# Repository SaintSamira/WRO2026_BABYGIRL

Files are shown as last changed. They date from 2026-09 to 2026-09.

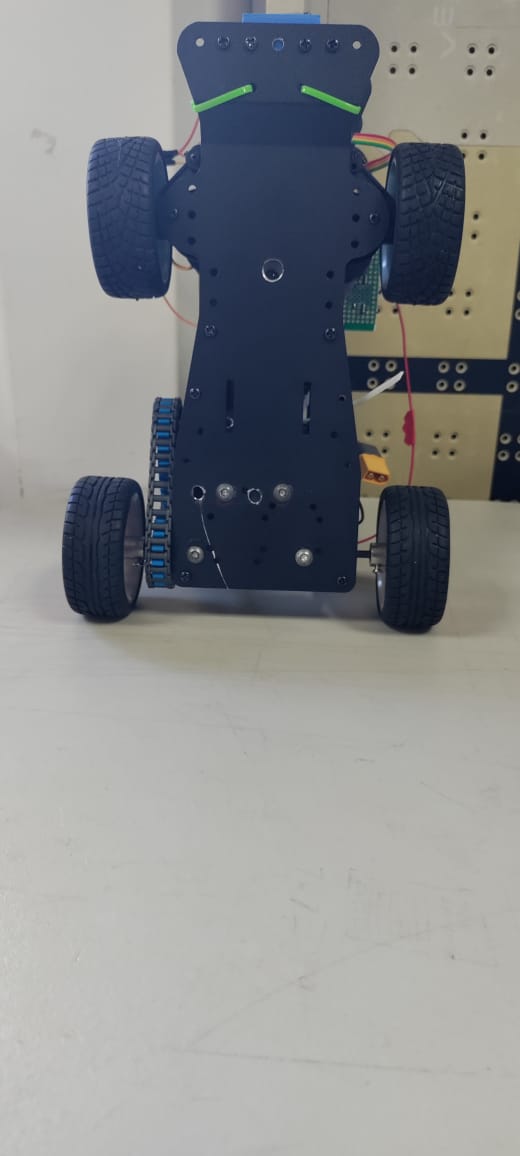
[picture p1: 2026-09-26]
v-photos/bottom.jpg

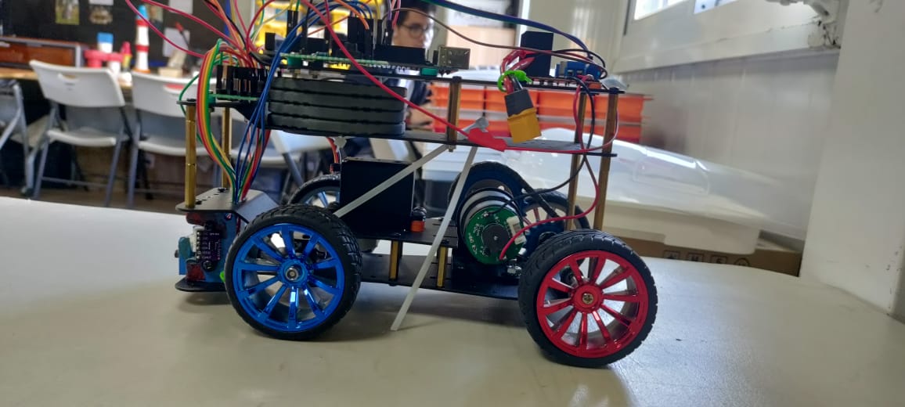
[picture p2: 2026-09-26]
v-photos/left.jpg

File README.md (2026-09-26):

# WRO Future Engineers 2026 — US Open
Autonomous self-driving vehicle engineering repository for the World Robot Olympiad Future Engineers category.
- Team: Bianca Polato & Samira Santos 
- Coach: Julian Vigil School: Howard Academy (Panama) 
- Event: WRO Future Engineers — US Open 2026
---

## Table of Contents
1. Team Introduction
2. The Challenge
3. Repository Structure
4. Mechanical Design
5. Electronics & Power Distribution
6. Software & Navigation Logic

## Team Introduction
Our team is composed of two members, working under the guidance of our coach, Julian Vigil.

- Bianca Polato - *Team Captain & Mechanical Lead*: Responsible for the physical build of the robot, including chassis assembly, mechanical integration, and hands-on electronics work such as soldering and wiring connections.
- Samira Santos - *Software Lead & Electronics Planning*: Responsible for programming the robot's control logic and computer vision, as well as planning the electronics architecture that Bianca implements physically.

This is our third year competing in WRO Future Engineers, and our first time qualifying for the Open. This program has always been, for us, about the process of learning: refining engineering reasoning, testing rigorously, and improving through iteration, rather than solely about the outcome of winning

## The Challenge
WRO Future Engineers challenges teams to design, build, and program a fully autonomous vehicle capable of navigating a reconfigurable race track without any human intervention or remote control once a round begins. The competition includes:
- **Open Challenge:** the vehicle must complete three consecutive laps around a track with a variable-size inner section, staying within the track boundaries.
- **Obstacle Challenge:** in addition to completing laps, the vehicle must identify and correctly respond to red and green traffic pillars along the track, and execute a parallel parking maneuver.
- **Suprise Challenge:** finally there was a recent addition to the rules. We are not sure on how what it is, but what we do know is that it involes a pedestrian cross walk.

Our current development priority is achieving a reliable, complete lap cycle in the Open Challenge before moving on to obstacle detection and parking.

## Repositiry Structure
- Model: includes all the digital models of the 3D printed bases we used.
- Schemes: includes a wiring diagrm of the electricl components of our vehicle.
- Src: includes the code we used for the detection and movement of the component in our vehicle
- t-photos: includes 2 fotos of the team.
- v-photos: includes fotos of the vehicle for different points of views.
- video: includes the car doing one lap.

## Mechanical Design
### Chassis
The V2.0 chassis is built on a modified metal car-building base kit (Olibots Arduino Advanced), which has been extensively adapted from its original configuration. This represents a complete departure from the LEGO SPIKE-based construction used in our earlier versions (V1.0 and V1.5), transitioning the team fully to open-source hardware and metal components.The wheels, steering servo, and L298N H-bridge motor driver were included with the Olibots kit. The metal axle and gears were reused from the school’s VEX V5 program.

The main structure consists of three metal plates connected by metal spacers. The middle plate was extensively modified: its rear section was cut out to create space for the DC motor mounted on the lower plate, while a central hole was added to accommodate the steering servo and allow it to connect to the front steering system. The lower plate was also modified by adding a central opening that provides access to the steering servo, allowing adjustments to be made without disassembling the entire chassis. Additional mounting holes were drilled into both all the plates to secure the L298N motor driver, I2C bus, Arduino board, servo motor and motor mount. Recently we added a four plate to add weight into the frontal area of the car.

### Steering System 
The vehicle uses an Ackermann-inspired front steering geometry, in which both front wheels turn at slightly different angles through the servo-actuated linkage, allowing smoother and more mechanically accurate cornering than a simple pivot-steering design.

### Drivetrain
Drive is provided by a Bringsmart JGB37-520 12V 30RPM DC gear motor, connected through a set of VEX V5 gears and a metal shaft to the rear axle. The L298N dual H-bridge module handles motor direction and speed control.

### Sensor Mounting
Two VL53L0X Time-of-Flight (ToF) laser distance sensors are mounted diagonally in a 3D-printed housing at the front of the vehicle. This housing was reused and adapted from a 3D print made in an earlier WRO season. Mounting the sensors diagonally at the front (rather than symmetrically on the sides, as in previous versions) reduces mechanical interference with the steering system while preserving detection range.

## Code Logic Explanation

The navigation code is written in C++ for the Arduino platform. It uses three VL53L0X time-of-flight distance sensors (left, front, right), a steering servo, a DC drive motor, and I2C communication with a NICLA Vision camera module that handles color detection.

### Hardware setup
- **Distance sensors:** The three VL53L0X sensors share the I2C bus. All VL53L0X units start with the same default address, so at startup every sensor is held in reset through its XSHUT pin (pins 7, 6, 5). The sensors are then woken one at a time and each is assigned a unique I2C address (0x30, 0x31, 0x32). After that, all three start continuous ranging.
- **Drive motor:** A single DC motor is controlled through an L298N H-bridge. ENA sets the speed with PWM, and IN1/IN2 set the direction. The normal driving speed is `DEFAULT_SPEED = 120`.
- Steering servo: The servo is on pin 8. It has a center position `(CENTER_ANGLE = 83)` and a safe range `(MIN_ANGLE = 48, MAX_ANGLE = 118)` to prevent over-steering.
- Start button and LED: A push button (`keyPin`, A3) starts the run, and an LED (`keyLed`, pin 13) turns on to confirm the button was pressed.

### Main loop flow
1. The robot stops the motor and waits for the start button.
2. `pre_side_def()` runs once at the start of the round. It decides both the round type and the turning direction of the track.
    - If the front sensor reads less than 150 mm (the robot starts facing a close wall, as in the parking-slot start), the round is treated as the Obstacle Challenge (`round_type = 'n'`). The direction is taken from the left wall: if it is closer than 150 mm the track turns right, otherwise it turns left.
    - Otherwise, the round is treated as the Open Challenge (`round_type = 'f'`). The robot drives forward while reading the left and right sensors. The first side whose distance exceeds 1000 mm (meaning that wall has ended) sets the turning direction, which is stored in `side` for the rest of the round.
3. Depending on `round_type`, the robot runs either `free_round()` (Open Challenge, no obstacles) or `non_free_round()` (Obstacle Challenge, with pillars and parking).
4. When the round ends, the robot resets and waits for the start button again.

### Corner detection and turning (`turn()`)
A corner is detected differently in each round:
- In the Open Challenge, it is detected when the side sensor in use reads more than 1000 mm (the side wall has ended).
- In the Obstacle Challenge, it is detected when the front sensor reads less than 600 mm (a wall is ahead).

Once a corner is detected, `turn()` executes a fixed maneuver:
1. It stops, increments the corner counter, and steers fully toward the turning direction (`MIN_ANGLE` for left turns, `MAX_ANGLE` for right turns).
2. It drives forward for 2.5 seconds.
3.It counter-steers for 0.8 seconds to straighten the car, then returns the servo to center.
4. It keeps driving until the relevant side sensor detects a wall again (distance under 500 mm), which confirms the turn is complete.

Wall-following (`free_round()`)
Between corners, the robot follows the side wall on the turning side using threshold-based steering:
- If the distance to the wall drops below 150 mm, it steers away from the wall.
- If the distance exceeds 200 mm, it steers back toward the wall.
- Each correction is held for 150 ms, and then the servo returns to center.
This repeats until 12 corners have been completed (3 laps of 4 corners each), which ends the round.

> Note: The code also includes calculatePID() and calculateP(). These are a proportional-integral-derivative controller (target 185 mm) and a simple proportional wall-following controller (target 200 mm), written as alternatives to the threshold-based steering that is currently active. They are in the code but not yet wired into the control loop. They are a planned refinement for smoother, more precise wall-following once the current logic is validated.

### Distance-based movement (`move_d()`)
For precise, short maneuvers such as parking, the robot uses dead reckoning: it moves a distance by running the motor for a calibrated amount of time.
- A calibration table (`CAL_DIST_MM` / `CAL_TIME_MS`) was built by measuring how far the robot traveled for different driving times at a fixed speed (`d_speed = 150`).
- `distanceToTimeMs()` converts a requested distance into a driving time by linear interpolation between the two nearest table points.
- For distances beyond the last calibrated point (1050 mm), it extrapolates using the average slope of the last three segments, so a single noisy measurement doesn't dominate.
- `move_d()` then runs the motor for that time and stops. A positive or negative distance selects the direction.

## Sensor & Vision Processing (NICLA Vision, Python/OpenMV)
The distance sensors, steering, and drive logic run on the Arduino. Obstacle and marker detection is handled separately by the NICLA Vision board, which runs MicroPython through the OpenMV IDE (`main.py`). The NICLA acts as an I2C slave at address 8 and continuously prepares an 18-byte data packet that the Arduino requests each cycle (see Object Avoidance Logic below).

## Run modes
The NICLA code has two modes, selected with `RUN_MODE` before flashing:
- `STANDALONE` runs detection and prints results to the serial monitor only, without using I2C. It is used for bench calibration and testing.
- `SLAVE` runs detection and sends the results to the Arduino over I2C. This mode must be active during competition runs.
  
## Camera setup
- The camera runs at a low resolution (QQVGA, 160×120 px) in RGB565 color format. This keeps the frame rate high enough for real-time driving decisions.
- Auto gain and auto white balance are disabled so color readings stay consistent as lighting changes. This is essential for reliable color-threshold detection.
- Only the bottom half of the frame is analyzed, since that is where nearby track objects appear. The top half, above the horizon, contains background clutter and is ignored. The bottom half is split into two Regions of Interest (ROIs):
  - Pillar ROI (upper part of the bottom half) is for upright objects: pillars and parking-slot walls.
  - Ground ROI (bottom strip) is for markings on the floor: crosswalk stripes.

## Color detection
All colors are detected with LAB color thresholds, tuned with OpenMV's built-in Threshold Editor. The values currently in the code are placeholders and must be recalibrated for the team's actual objects and the competition lighting before testing.
- **Red and green pillars (`find_pillars()`):** For each color, the code finds all matching blobs in the pillar ROI and keeps only the largest one, assuming it is the closest pillar of that color. Both colors are reported independently, so the Arduino can receive a red and a green pillar in the same frame.
- **Magenta parking slot (`find_magenta()`):** This works in one of two modes.
In gap mode, both parking walls are visible as separate blobs, and the target is the midpoint between them.
In single-blob mode, only one wall is visible, and its width is used to estimate distance.
- **Yellow crosswalk stripes (`find_crosswalk()`):** Yellow blobs in the ground ROI are first filtered by shape (their width-to-height ratio must look like a stripe). A crosswalk is only confirmed if at least 3 stripes are found and they are spaced at fairly regular intervals. This rejects random yellow noise.

## Distance estimation
The distance to each detected object is estimated with the pinhole-camera relationship:
> distance = (real object width × focal length in pixels) / apparent width in pixels

The known real sizes are:
- pillar width: 50 mm
- parking wall: 200 mm
- stripe thickness: 15 mm
The focal length is `FOCAL_LENGTH_PX = 157`. These values must match the team's actual objects and camera setup. In gap mode the parking slot has no single known-width reference, so no distance is sent for it.

## Sending data to the Arduino
Each frame, the detection results are packed into a fixed 18-byte binary packet with struct.pack('<BHHHHHHHH', ...), plus a checksum byte. It uses the same little-endian layout as the VisionPacket struct on the Arduino side, so the two boards exchange data directly without extra parsing.

Any missing value is sent as 0xFFFF. The I2C slave buffer is refreshed with new data every frame, so whenever the Arduino requests data it receives the most recently processed frame's results.

## Parking Logic (Parallel Parking)
The code already contains two parking routines built on the distance-based movement described above:
- `move_out()` drives the robot out of the parking slot at the start of the Obstacle Challenge. It uses a sequence of steering angles and timed moves that differs depending on the turning direction.
- `move_in()` parks the robot at the end of the round. It drives past the slot, reverses into it at an angle, straightens while reversing, and makes a final forward adjustment.
Both routines are currently "blind": they follow fixed timed sequences and do not yet use the camera's parking_cx data. They are also not called from the main loop yet. The point where the 12th corner is completed in non_free_round() is marked as the entry point for parking.

## Object Avoidance Logic
The Obstacle Challenge round (`non_free_round()`) uses the same corner-turning logic as the Open Challenge, and adds data from the NICLA Vision module.

**How it works**
1. **Request data:** On each control cycle (about every 150 ms), the Arduino requests the 18-byte packet from the NICLA at I2C address 8.
2. **Validate:** The Arduino recalculates the XOR checksum. If it doesn't match, or if fewer than 18 bytes arrive, the packet is discarded for that cycle and an error is printed to the serial monitor. This prevents corrupted data from causing bad steering decisions.
3. **Corners:** If the front sensor reads less than 600 mm, the robot treats this as approaching a corner and hands off to `turn()`.
4. **Vision flags:** The robot then checks each flag in the packet independently:
     - **Red pillar:** The official WRO rule requires red pillars to be passed on their right side. The position (`red_cx`) and distance are available for steering.
      - **Green pillar:** The official WRO rule requires green pillars to be passed on their left side. The position (`green_cx`) and distance are available for steering.
      - **Parking slot:** Its position is available for aligning the parking maneuver.
      - **Crosswalk:** The required action depends on the WRO surprise rule, which has not been officially revealed yet. The robot only logs the detection for now.

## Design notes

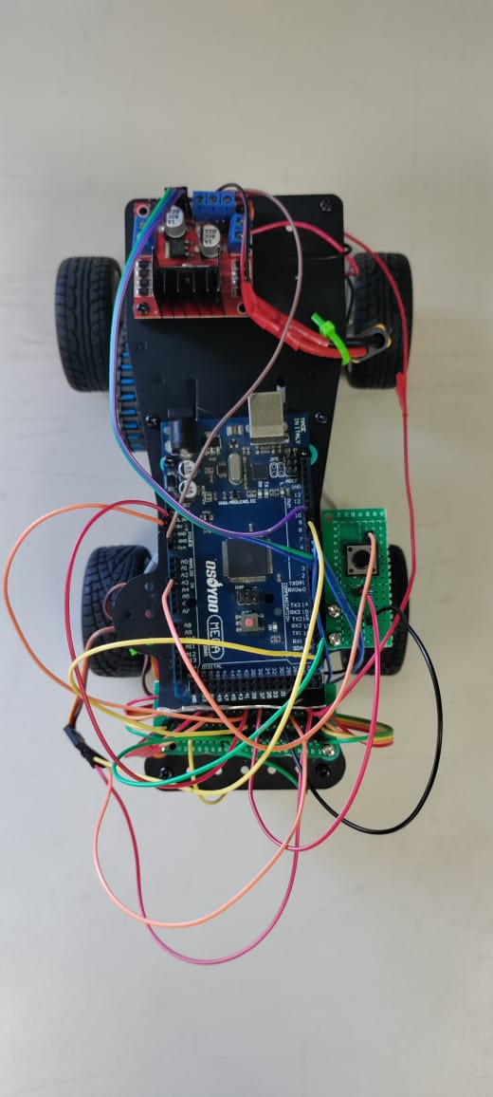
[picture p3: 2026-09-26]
v-photos/top.jpg

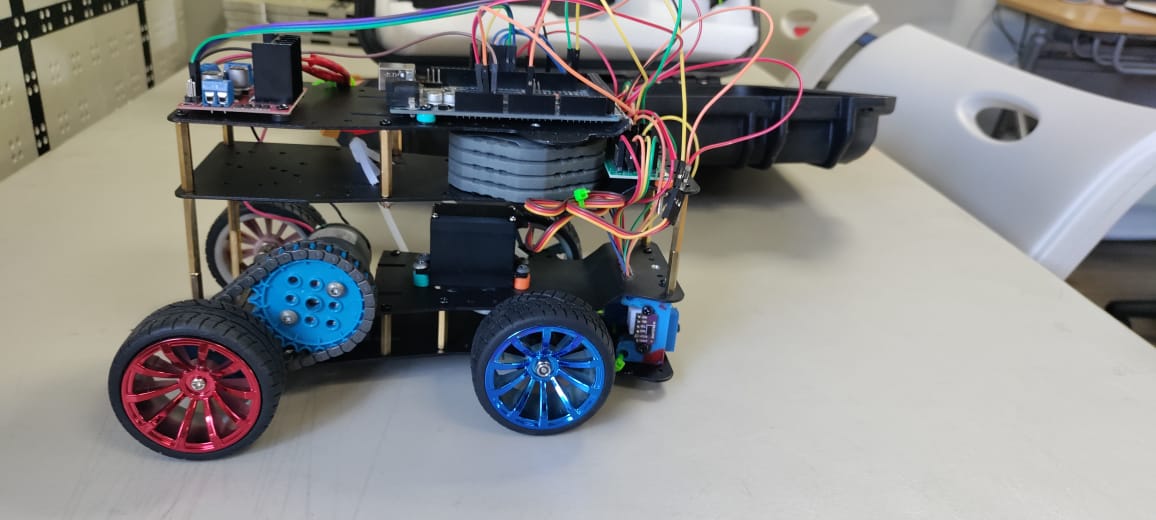
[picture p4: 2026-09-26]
v-photos/right.jpg

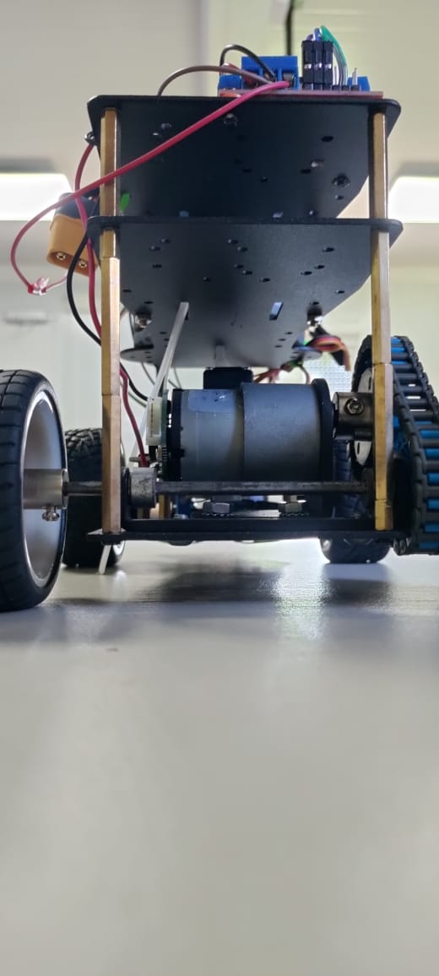
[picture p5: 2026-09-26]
v-photos/back.jpg

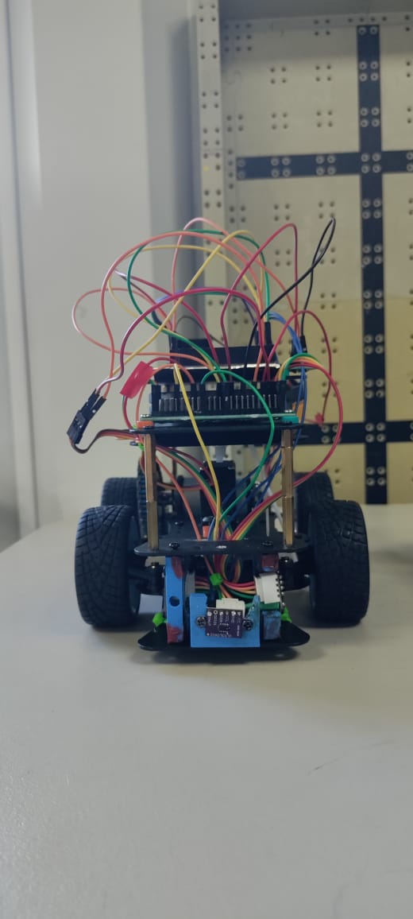
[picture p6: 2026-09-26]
v-photos/front.jpg

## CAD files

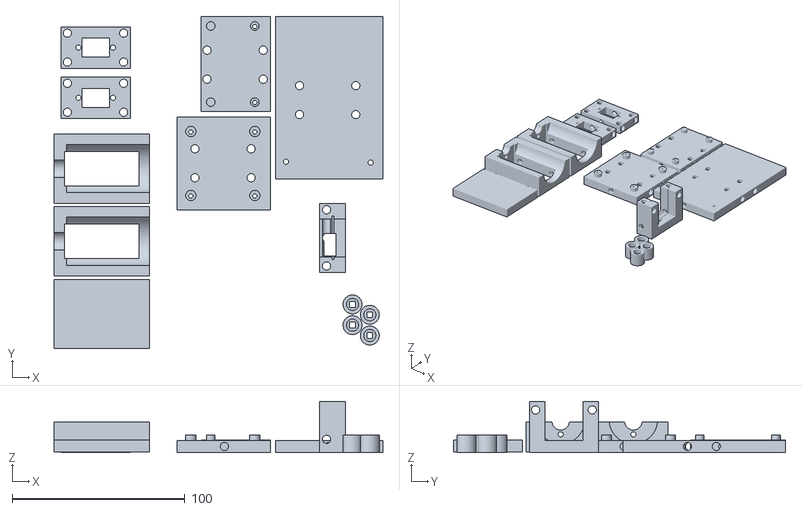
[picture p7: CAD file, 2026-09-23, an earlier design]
model/FE - 2025 HA_LEGACY (Lego Implement).stl
190.0 x 192.0 x 29.5

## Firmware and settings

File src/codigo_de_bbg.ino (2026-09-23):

#include <Servo.h>        // Library to control the steering servo
//#include <SoftwareSerial.h>
#include <Wire.h>         // I2C communication (distance sensors + Nicla camera)
#include <VL53L0X.h>      // Library for the VL53L0X time-of-flight distance sensors

// ---------------------------------------------------------------------------
//  Vision data packet sent by the Nicla Vision camera
// ---------------------------------------------------------------------------
// #pragma pack(1) removes padding between fields so the struct in memory has
// exactly the same byte layout as the packet the camera sends (18 bytes).
#pragma pack(1)
struct VisionPacket {
    uint8_t  status_flags;          // Bit flags: which objects were detected (see FLAG_* below)
    uint16_t red_cx;                // Horizontal center (x pixel) of the red pillar in the image
    uint16_t red_distance_mm;       // Estimated distance to the red pillar in millimeters
    uint16_t green_cx;              // Horizontal center (x pixel) of the green pillar
    uint16_t green_distance_mm;     // Estimated distance to the green pillar in millimeters
    uint16_t parking_cx;            // Horizontal center (x pixel) of the magenta parking slot
    uint16_t parking_distance_mm;   // Estimated distance to the parking slot (may be NOT_FOUND_SENTINEL)
    uint16_t yellow_closest_mm;     // Distance to the closest yellow crosswalk stripe
    uint16_t yellow_farthest_mm;    // Distance to the farthest yellow crosswalk stripe
    uint8_t  checksum;              // XOR of all previous bytes, used to verify the packet is not corrupted
};
#pragma pack()   // Restore the compiler's normal struct packing

// Bit masks used to read status_flags (each bit = one detected object)
#define FLAG_RED     0x01   // Bit 0: red pillar detected
#define FLAG_GREEN   0x02   // Bit 1: green pillar detected
#define FLAG_PARKING 0x04   // Bit 2: magenta parking slot detected
#define FLAG_YELLOW  0x08   // Bit 3: yellow crosswalk stripes detected
#define NOT_FOUND_SENTINEL 0xFFFF   // Special value meaning "distance not available"

#define NICLA_I2C_ADDR 8   // I2C address of the Nicla Vision camera (the old 0x12 value is no longer used)
#define PACKET_SIZE sizeof(VisionPacket)  // Size of the vision packet in bytes (must equal 18)

VisionPacket packet;   // Global copy of the vision packet (note: non_free_round() uses its own local copy)

// ---------------------------------------------------------------------------
//  Steering servo and sensor index constants
// ---------------------------------------------------------------------------
Servo myservo;         // Steering servo object
const int l = 0;       // Index of the LEFT distance sensor
const int f = 1;       // Index of the FRONT distance sensor
const int r = 2;       // Index of the RIGHT distance sensor
double Fdist = 300, Ldist = 300, Rdist = 300; // Last readings (mm) of front/left/right sensors; 300 = placeholder start values

// Servo angle references (degrees). Values were calibrated on the real robot.
const int CENTER_ANGLE  = 83;   // Wheels straight (previously 91)
const int MIN_ANGLE     = 48;   // Maximum steering to one side (about -35 from center)
const int MAX_ANGLE     = 118;  // Maximum steering to the other side (about +35 from center)

// ---------------------------------------------------------------------------
//  VL53L0X distance sensors
// ---------------------------------------------------------------------------
VL53L0X sensors[3];                                  // Array of the 3 distance sensors (left, front, right)
const int xshutPins[]     = {7, 6, 5};               // XSHUT (reset/enable) pin of each sensor: left, front, right
const uint8_t addresses[] = {0x30, 0x31, 0x32};      // Unique I2C address assigned to each sensor at startup
                                                     // (all VL53L0X start with the same address, so each one must be changed;
                                                     //  these must not conflict with other I2C devices such as the Nicla)

// ---------------------------------------------------------------------------
//  Start button and status LED
// ---------------------------------------------------------------------------
const int keyPin = A3;   // Pin where the start button is connected
const int keyLed = 13;   // LED that turns on to confirm the button was pressed
int buttonState = 0;     // Last value read from the button (HIGH = pressed)

// ---------------------------------------------------------------------------
//  L298 motor driver control pins
// ---------------------------------------------------------------------------
const int ENA = 10;  // PWM pin that sets the motor speed (0-255)
const int IN1 = 3;   // Direction pin A
const int IN2 = 4;   // Direction pin B

const int DEFAULT_SPEED = 120;   // Normal driving speed (PWM value)
const int TURNING_SPEED = 80;    // Slower speed intended for turns (currently not used)

// ---------------------------------------------------------------------------
//  Race state variables
// ---------------------------------------------------------------------------
char  side        = ' ';   // Turning direction of the track: 'l' = left, 'r' = right, ' ' = unknown yet
short corners     = 0;     // Number of corners completed (12 corners = 3 laps)
int   actual_Dist = 0;     // Current distance to the side wall (mm)
int   prev_Dist   = 0;     // Previous distance to the side wall (mm)
bool  run         = false; // true once the start button has been pressed
char round_type   = ' ';   // Round type: 'f' = free round (no obstacles), 'n' = non-free round (obstacles)

// ---------------------------------------------------------------------------
//  PID configuration (wall following)
// ---------------------------------------------------------------------------
double setpoint = 185.0;   // Desired distance to the side wall in mm
double error;              // Global error variable (calculatePID() uses its own local one)

// ---------------------------------------------------------------------------
//  Distance-to-time calibration table
// ---------------------------------------------------------------------------
// Each pair means: "driving for CAL_TIME_MS milliseconds moved the robot
// CAL_DIST_MM millimeters" at the calibration speed (d_speed).
const float CAL_DIST_MM[] = {   0,  10, 100, 250, 450,  560,  900, 1050 };   // Measured distances (mm)
const float CAL_TIME_MS[] = {   0, 100, 250, 500, 750, 1000, 1250, 1500 };   // Driving time that produced each distance (ms)
const int   CAL_POINTS    = sizeof(CAL_DIST_MM) / sizeof(CAL_DIST_MM[0]);    // Number of calibration points (8)
const int   d_speed       = 150;   // Motor speed used during calibration (and by move_d())

// Slope (ms per mm) used for distances longer than the last calibration point.
// It is averaged over the last 3 segments so one noisy measurement doesn't dominate.
const float EXTRAP_MS_PER_MM =
    (CAL_TIME_MS[CAL_POINTS - 1] - CAL_TIME_MS[CAL_POINTS - 4]) /
    (CAL_DIST_MM[CAL_POINTS - 1] - CAL_DIST_MM[CAL_POINTS - 4]);

// ===========================================================================
//  distanceToTimeMs()
//  Converts a positive distance (mm) into the driving time (ms) needed to
//  travel it, using linear interpolation on the calibration table.
// ===========================================================================
unsigned long distanceToTimeMs(float abs_distance) {
  if (abs_distance <= 0) return 0;   // No distance = no movement

  const float last_d = CAL_DIST_MM[CAL_POINTS - 1];   // Largest calibrated distance
  const float last_t = CAL_TIME_MS[CAL_POINTS - 1];   // Time for the largest calibrated distance
  float t;                                            // Resulting time in ms

  if (abs_distance >= last_d) {
    // Beyond the table: extrapolate using the average slope of the last segments
    t = last_t + (abs_distance - last_d) * EXTRAP_MS_PER_MM;
  } else {
    // Find the table segment [i-1, i] that contains this distance
    int i = 1;
    while (i < CAL_POINTS - 1 && abs_distance > CAL_DIST_MM[i]) i++;

    float d0 = CAL_DIST_MM[i - 1], d1 = CAL_DIST_MM[i];   // Segment start/end distances
    float t0 = CAL_TIME_MS[i - 1], t1 = CAL_TIME_MS[i];   // Segment start/end times

    // Linear interpolation between the two points
    t = t0 + (abs_distance - d0) * (t1 - t0) / (d1 - d0);
  }
  return (unsigned long)(t + 0.5f);   // Round to the nearest millisecond
}

// ===========================================================================
//  move_d()
//  Drives a given distance in mm (positive or negative sign selects the
//  direction) by running the motor for the calibrated time. Blocking.
// ===========================================================================
void move_d(float distance_mm) {
  int direction = (distance_mm >= 0) ? -1 : 1;                       // Sign convention: positive distance -> negative motor speed
  unsigned long move_time_ms = distanceToTimeMs(fabs(distance_mm));  // How long to drive

  if (move_time_ms == 0) return;   // Nothing to do

  move(direction * d_speed);   // Start the motor at calibration speed
  delay(move_time_ms);         // Wait while the robot moves (blocking)
  stop();                      // Stop the motor
}

// ===========================================================================
//  stop()
//  Stops the drive motor: speed 0 and both direction pins LOW.
// ===========================================================================
void stop() {
  analogWrite(ENA, 0);       // PWM speed = 0
  digitalWrite(IN1, LOW);    // Release direction pin A
  digitalWrite(IN2, LOW);    // Release direction pin B
}

// ===========================================================================
//  move(speed)
//  Starts the motor at the given speed and keeps it running (non-blocking).
//  speed > 0 : IN1 HIGH / IN2 LOW
//  speed < 0 : IN1 LOW  / IN2 HIGH
//  speed = 0 : stop
// ===========================================================================
void move(int speed)
{
  Serial.print ("Move speed :");   // Debug output
  Serial.print (speed);
  if (speed > 0)
  {
    digitalWrite(IN1, HIGH);   // Direction for positive speed
    digitalWrite(IN2, LOW);
  } else if (speed < 0) {
    digitalWrite(IN1, LOW);    // Direction for negative speed
    digitalWrite(IN2, HIGH);
  } else {
    stop();                    // Speed 0 -> stop and exit
    return;
  }

  analogWrite(ENA, abs(speed));   // Apply the speed magnitude as PWM
}

// ===========================================================================
//  move(speed, duration_ms)
//  Overloaded version: moves at a speed for a fixed time, then stops.
//  + = forward, - = backward
//  NOTE: the direction pins here are the OPPOSITE of move(speed) above.
// ===========================================================================
void move(int speed, int duration_ms) {
  //speed = constrain(speed, -255, 255);

  if (speed > 0) {
    digitalWrite(IN1, LOW);    // Forward
    digitalWrite(IN2, HIGH);
  } else if (speed < 0) {
    digitalWrite(IN1, HIGH);   // Backward
    digitalWrite(IN2, LOW);
  } else {
    stop();
    return;
  }

  analogWrite(ENA, abs(speed));   // Apply speed
  delay(duration_ms);             // Keep moving for the requested time (blocking)
  stop();                         // Then stop
}

// ===========================================================================
//  dist()
//  Returns the distance (mm) read by one sensor: l, f or r.
// ===========================================================================
double dist (int space)
{
  return sensors[space].readRangeContinuousMillimeters();
}

// ===========================================================================
//  turn_d()
//  Moves the steering servo to an angle and waits 0.5 s for it to arrive.
// ===========================================================================
void turn_d(int val)
{
  myservo.write(val);   // Set steering angle
  delay(500);           // Give the servo time to reach the position
}

// ===========================================================================
//  turn()
//  Corner maneuver: steers into the corner, counter-steers to straighten,
//  then waits until the side wall is visible again.
// ===========================================================================
void turn()
{
  stop();                // Stop before starting the corner
  delay(100);
  corners++;             // Count this corner
  // Steer toward the turn direction (MIN_ANGLE for left, MAX_ANGLE for right)
  myservo.write(side=='l'? MIN_ANGLE: MAX_ANGLE);
  Serial.print("Corner :");
  Serial.println (corners);
  move(DEFAULT_SPEED);   // Drive through the corner
  delay(2500);           // Time spent turning (tuned by testing)
  // Counter-steer briefly to straighten the car
  myservo.write(side=='l'? MAX_ANGLE: MIN_ANGLE);
  delay (800);
  myservo.write(CENTER_ANGLE);   // Wheels straight
  // Keep driving until the side wall is closer than 500 mm (out of the corner)
  while (dist(side == 'l'? l: r) > 500)
    {
    delay (50);
    continue;
    }
  Serial.println ("OUT corner ");
}

// ===========================================================================
//  pre_side_def()
//  Runs at the start of the race. Decides the round type (free or
//  non-free) and the turning direction of the track (left or right).
// ===========================================================================
void pre_side_def()
{
  // First reading of all three sensors
  Ldist = dist(l);
  Rdist = dist(r);
  Fdist = dist(f);
  Serial.println(Fdist);
  // If something is very close in front (< 150 mm) -> non-free round, otherwise free round
  round_type = (Fdist < 150? 'n': 'f');
  side = ' ';
  if (round_type == 'n')
    {
      // Non-free round: decide direction from the left wall distance
      side = (Ldist < 150? 'r': 'l')  ;
    }
  else
    {
        side =' ';   // Free round: direction still unknown
    }
  // If direction is unknown, drive forward until a side opens up (corner found)
  while (side == ' ')
  {
   move(DEFAULT_SPEED);
   Ldist = dist(l);
   Rdist = dist(r);
   Fdist = dist(f);
   Serial.println("LRF");   // Debug: print left, right, front readings
   Serial.println(Ldist);
   Serial.println(Rdist);
   Serial.println(Fdist);
      // A reading over 1000 mm means there is no wall on that side -> that is the corner
      if ((Ldist > 1000) || (Rdist > 1000))
      {
            stop();
            side = (Ldist > 500? 'l': 'r');   // Open side = turning direction
            Serial.println(side);
      }
  }
}

// ===========================================================================
//  calculatePID()
//  PID controller for wall following. Returns the servo angle needed to keep
//  the robot at 'setpoint' mm from the wall on the given side.
//  (Currently not called: its use in free_round() is commented out.)
// ===========================================================================
int calculatePID(double current_distance, char side) {
    static double last_error = 0;   // Error from the previous call (kept between calls)
    static double integral = 0;     // Accumulated error (kept between calls)

    // Tuning constants (these need to be adjusted by testing)
    double Kp = 0.066;  // Proportional gain
    double Ki = 0.01;   // Integral gain
    double Kd = 0.05;   // Derivative gain

    double error = setpoint - current_distance;   // Positive = too close to the wall

    // 1. Proportional term: reacts to the current error
    double P_out = error * Kp;

    // 2. Integral term: reacts to accumulated error, capped to prevent "windup"
    integral += error;
    if (integral > 50) integral = 50;
    if (integral < -50) integral = -50;
    double I_out = integral * Ki;

    // 3. Derivative term: reacts to how fast the error is changing
    double D_out = (error - last_error) * Kd;
    last_error = error;

    double total_correction = P_out + I_out + D_out;   // Combined correction

    // Apply the correction around the center angle; sign depends on the wall side
    int target_angle = CENTER_ANGLE;
    if (side == 'r') {
        target_angle += (int)total_correction;
    } else {
        target_angle -= (int)total_correction;
    }

    // Keep the angle inside the servo's safe range
    if (target_angle < MIN_ANGLE) target_angle = MIN_ANGLE;
    if (target_angle > MAX_ANGLE) target_angle = MAX_ANGLE;

    return target_angle;
}

// ===========================================================================
//  calculateP()
//  Simpler proportional-only controller for wall following (target 200 mm).
//  Returns a servo angle. (Currently not called anywhere.)
// ===========================================================================
int calculateP(double current_distance, char side) {
    // Local setpoint; tuning differs from the PID because it is not time-scaled
    const double setpoint = 200.0;

    double error = setpoint - current_distance;   // Positive = too close to the wall

    int target_angle = CENTER_ANGLE;
    // Correction proportional to the relative error, up to about ±15 degrees
    if (side == 'l')
      target_angle += (int)(error/setpoint * 15);
    else
      target_angle -= (int)(error/setpoint * 15);
    return constrain(target_angle, MIN_ANGLE, MAX_ANGLE);   // Keep inside servo limits
}

// ===========================================================================
//  free_round()
//  Open challenge (no obstacles): follows the outer wall and turns at each
//  corner until 12 corners (3 laps) are completed.
// ===========================================================================
void free_round()
{
  corners = 0;
  prev_Dist = (side == 'l') ? dist(l) : dist(r);   // Initial distance to the wall being followed
  while (corners < 12)                             // 12 corners = 3 laps
  {
    move(DEFAULT_SPEED);   // Keep driving

    actual_Dist = (side == 'l') ? dist(l) : dist(r);   // Distance to the followed wall

    // Wall disappeared (> 1000 mm) -> we reached a corner
    if (actual_Dist > 1000)
      {
        stop();
        turn();
      }

    if (side == 'l')
        {
          // Wall following on the LEFT side (bang-bang steering)
          actual_Dist = dist(l);
          while (actual_Dist <= 1000)   // Repeat while the wall is visible
          {
            actual_Dist = dist(l);
            if (actual_Dist < 150)          // Too close -> steer away from the wall
              myservo.write(MAX_ANGLE);
            else if (actual_Dist > 200)     // Too far -> steer toward the wall
              myservo.write(MIN_ANGLE);
            delay (150);                    // Hold the correction briefly
            myservo.write(CENTER_ANGLE);    // Straighten the wheels again
          }
        }
    else
        {
          // Wall following on the RIGHT side (mirror of the left logic)
          actual_Dist = dist(r);
          while (actual_Dist <= 1000)
          {
            actual_Dist = dist(r);
            if (actual_Dist < 150)          // Too close -> steer away
              myservo.write(MIN_ANGLE);
            else if (actual_Dist > 200)     // Too far -> steer toward the wall
              myservo.write(MAX_ANGLE);
            delay (150);
            myservo.write(CENTER_ANGLE);
          }
        // Alternative: normal PID control (disabled)
        /*int servoPos = calculatePID(actual_Dist, side);
        myservo.write(servoPos);
        */
        //Serial.println(servoPos);
      }
    prev_Dist = actual_Dist;   // Save reading for the next cycle
  }
  stop();   // Race finished
}
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
void loop()
{
  stop();                       // Motor off while waiting
  digitalWrite(keyLed, LOW);    // LED off = not started
  while (!run)                  // Wait for the start button
  {
    buttonState = digitalRead(keyPin);
    if(buttonState == HIGH )
      {
        run = true;                  // Button pressed -> start
        digitalWrite(keyLed, HIGH);  // LED on to confirm
        delay(1000);                 // Short pause before moving
        break;
      }
    else
      run = false;

    Serial.write("\nWaiting button...");
    delay(100);
  }
  /////////////////
  // Test area after the button press (for quick experiments)

  ///////////////
    stop();
    // Sensor debug loop — disabled with while(false); change to while(true) to print readings every second
    while (false)
    {
    Ldist = dist(l);
    Rdist = dist(r);
    Fdist = dist(f);
    Serial.println("LRF");
    Serial.println(Ldist);
    Serial.println(Rdist);
    Serial.println(Fdist);
    delay(1000);
    }

    pre_side_def();               // Decide round type and turning direction
  Serial.println (round_type) ;
    if (round_type == 'n' )
      {
      non_free_round();           // Obstacle challenge
      }
    else if (round_type == 'f')
      {
      free_round();               // Open challenge
      }
    run = false;                  // Reset so the robot waits for the button again
    buttonState = 0;
}   // End of loop() (this closing brace was missing in the original code)

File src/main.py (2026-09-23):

# ============== NICLA VISION - PYTHON ==============
# Save as main.py on the Nicla Vision (OpenMV IDE).
#
# MODE_STANDALONE: runs detection + Serial print only, no I2C. Use this for
#                   bench calibration and isolated testing before wiring to Mega.
# MODE_SLAVE:       runs detection + I2C slave buffer updates for the Mega to poll.
#
# No ToF/distance-sensor code exists or has ever existed in this file —
# all distance estimates are vision-based (known-width-to-pixel-width formula).

import sensor
import image
import time
from pyb import I2C
import struct

# =========================================================================
# MODE FLAG — set before flashing.
# =========================================================================
MODE_STANDALONE = "STANDALONE"
MODE_SLAVE      = "SLAVE"
RUN_MODE = MODE_STANDALONE   # <-- flip to MODE_SLAVE only after standalone testing passes clean

I2C_SLAVE_ADDR = 8  # must match Mega's I2C_SLAVE_ADDRESS

print("RUN_MODE active:", RUN_MODE)  # sanity check — must appear immediately on boot

# =========================================================================
# Camera Configuration
# =========================================================================
sensor.reset()
sensor.set_pixformat(sensor.RGB565)
sensor.set_framesize(sensor.QQVGA)
sensor.skip_frames(time=2000)
sensor.set_auto_gain(False)
sensor.set_auto_whitebal(False)

FRAME_W = sensor.width()
FRAME_H = sensor.height()

# =========================================================================
# CALIBRATION REQUIRED — recalibrate via OpenMV IDE Threshold Editor
# =========================================================================
GREEN_THRESHOLD   = (30, 80, -70, -30, 0, 70)   # [Guessing] placeholder, from your file
RED_THRESHOLD     = (30, 80, 30, 80, 10, 70)     # [Guessing] placeholder, from your file
MAGENTA_THRESHOLD = (20, 80, 30, 80, -60, -10)   # [Guessing] carried over — recalibrate at QQVGA
YELLOW_THRESHOLD  = (60, 100, -10, 30, 30, 90)   # [Guessing] no official spec published yet

FOCAL_LENGTH_PX = 157.0  # [Likely] your prior calibrated value — preserved, do not overwrite blindly

# =========================================================================
# KNOWN GEOMETRY (mm) — from WRO 2026 ruleset where cited, else placeholder
# =========================================================================
PILLAR_WIDTH_MM   = 50    # rule 13.1 — confirmed
DELIMITER_LONG_MM = 200   # rule 13.7 — assumes long face visible to camera [Guessing]
STRIPE_WIDTH_MM   = 15    # 1.5 cm — short edge/thickness [Guessing on axis mapping]
STRIPE_LENGTH_MM  = 100   # 10 cm  — long edge/span       [Guessing on axis mapping]
STRIPE_ASPECT_RATIO = STRIPE_LENGTH_MM / STRIPE_WIDTH_MM  # ~6.7
STRIPE_ASPECT_TOLERANCE = 0.5  # [Guessing] wide net — tighten once real footage exists
MIN_STRIPE_COUNT = 3  # [Guessing]

def estimate_distance(pixel_dim, real_dim_mm, focal_px=FOCAL_LENGTH_PX):
    if pixel_dim <= 0:
        return -1
    return int((real_dim_mm * focal_px) / pixel_dim)

# =========================================================================
# ROIs — computed from actual frame size, not hardcoded resolution
# =========================================================================
band_top = FRAME_H // 2
pillar_roi_h = (FRAME_H - band_top) * 2 // 3
pillar_roi = (0, band_top, FRAME_W, pillar_roi_h)                              # upright objects
ground_roi = (0, band_top + pillar_roi_h, FRAME_W, FRAME_H - band_top - pillar_roi_h)  # ground-plane stripes

# =========================================================================
# Detection functions
# =========================================================================
def find_pillars(img):
    results = []
    for thresh, name in [(RED_THRESHOLD, "RED"), (GREEN_THRESHOLD, "GREEN")]:
        blobs = img.find_blobs([thresh], roi=pillar_roi, pixels_threshold=60,
                                area_threshold=60, merge=True)
        if blobs:
            b = max(blobs, key=lambda x: x.pixels())
            results.append({"id": name, "cx": b.cx(), "w": b.w(),
                             "distance_mm": estimate_distance(b.w(), PILLAR_WIDTH_MM),
                             "blob": b})
    return results

def find_magenta(img):
    blobs = img.find_blobs([MAGENTA_THRESHOLD], roi=pillar_roi, pixels_threshold=30,
                            area_threshold=30, merge=False)
    if not blobs:
        return None
    if len(blobs) >= 2:
        top2 = sorted(blobs, key=lambda b: b.pixels(), reverse=True)[:2]
        left, right = sorted(top2, key=lambda b: b.cx())
        return {"cx": (left.cx() + right.cx()) // 2, "mode": "gap",
                "left": left, "right": right}
    b = blobs[0]
    return {"cx": b.cx(), "mode": "single_blob", "w": b.w(), "blob": b}

def _is_stripe_shaped(b):
    if b.h() <= 0:
        return False
    ratio = b.w() / b.h()
    lo = STRIPE_ASPECT_RATIO * (1 - STRIPE_ASPECT_TOLERANCE)
    hi = STRIPE_ASPECT_RATIO * (1 + STRIPE_ASPECT_TOLERANCE)
    return lo <= ratio <= hi

def find_crosswalk(img):
    raw_blobs = img.find_blobs([YELLOW_THRESHOLD], roi=ground_roi, pixels_threshold=15,
                                area_threshold=15, merge=False)
    blobs = [b for b in raw_blobs if _is_stripe_shaped(b)]
    if len(blobs) < MIN_STRIPE_COUNT:
        return {"detected": False, "blobs": []}
    blobs = sorted(blobs, key=lambda b: b.cx())
    gaps = [blobs[i+1].cx() - blobs[i].cx() for i in range(len(blobs) - 1)]
    avg_gap = sum(gaps) / len(gaps)
    gap_var = sum(abs(g - avg_gap) for g in gaps) / len(gaps)
    if gap_var >= (avg_gap * 0.6):
        return {"detected": False, "blobs": []}
    return {"detected": True, "blobs": blobs}

def build_detection_report(pillars, magenta, crosswalk):
    report = {
        "red_pillar":    {"found": False, "cx": None, "distance_mm": None},
        "green_pillar":  {"found": False, "cx": None, "distance_mm": None},
        "parking_slot":  {"found": False, "cx": None, "distance_mm": None},
        "yellow_stripes":{"found": False, "closest_mm": None, "farthest_mm": None}
    }
    for p in pillars:
        key = "red_pillar" if p["id"] == "RED" else "green_pillar"
        report[key] = {"found": True, "cx": p["cx"], "distance_mm": p["distance_mm"]}

    if magenta:
        dist = estimate_distance(magenta["w"], DELIMITER_LONG_MM) if magenta["mode"] == "single_blob" else None
        report["parking_slot"] = {"found": True, "cx": magenta["cx"], "distance_mm": dist}

    if crosswalk["detected"]:
        distances = [estimate_distance(b.h(), STRIPE_WIDTH_MM) for b in crosswalk["blobs"]]
        distances = [d for d in distances if d > 0]
        if distances:
            report["yellow_stripes"] = {"found": True, "closest_mm": min(distances),
                                         "farthest_mm": max(distances)}
    return report
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
